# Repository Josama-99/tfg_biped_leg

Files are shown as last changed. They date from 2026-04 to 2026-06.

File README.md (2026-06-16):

# tfg_biped_leg

Bipedal robot leg control using ODrive motor controllers.

## Overview

This package provides control for a 3-DOF bipedal robot leg using:
- **Raspberry Pi** as main controller
- **ODrive v3.6** for motor control
- **TCA9548A** I2C multiplexer
- **AS5600** magnetic encoders for joint position sensing

**Current Status**: Official ODrive working ✅, TCA9548A + AS5600 encoder reading ✅ (with software filter), Makerbase BRICKED ⚠️

# CAD Models

The complete CAD models are available publicly on Onshape:

- Full robot assembly:
https://cad.onshape.com/documents/045d4f9be7d4b5f849aa776b/w/4ef7c623f6d94cfc82375378/e/659acbeabc324ef1581e169c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

- URDF model:
https://cad.onshape.com/documents/ea220f3303c98d0806fc4f15/w/99e78a21887813d82aa56a5b/e/c44cd6904376fa166963b570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

## Architecture

```
┌──────────────────────────────────────────────────────────────────────────────┐
│                              Raspberry Pi                                    │
│  ┌──────────────┐   ┌──────────────┐  ┌──────────────┐  ┌──────────────────┐ │
│  │ Official     │   │ Makerbase    │  │ I2C Mux      │  │ Control Logic    │ │
│  │ ODrive v3.6  │   │ M1 M22015    │  │              │  │                  │ │
│  │ (1 motor)    │   │ (2 motors)   │  │ (Encoders)   │  │                  │ │
│  └──────┬───────┘   └──────┬───────┘  └──────┬───────┘  └──────┬───────────┘ │
└─────────┼──────────────────┼─────────────────┼─────────────────┼─────────────┘
          │                  │                 │                 │
          ▼                  ▼                 ▼                 │
     ┌──────────┐      ┌──────────┐      ┌──────────┐            │
     │ Official │      │ Makerbase│      │TCA9548A  │◄───────────┘
     │ ODrive   │      │ ODrive   │      │I2C Mux   │
     └────┬─────┘      └────┬─────┘      └────┬─────┘
          │                 │                 │
          ▼                 ▼                 ▼
       ┌──────────┐     ┌──────────┐      ┌──────────┬──────────┬──────────┐
       │ D5065    │     │ D5065    │      │ AS5600   │ AS5600   │ AS5600   │
       │ (Hip1)   │     │ (Hip2 +  │      │ (Hip1)   │ (Hip2)   │ (Knee)   │
       │          │     │  Knee)   │      │          │          │          │
       └──────────┘     └──────────┘      └──────────┴──────────┴──────────┘
```

## Hardware

### Current Test Setup (Dual ODrive, 3 Motors)
| Component | Model | Value | Status |
|---|---|---|---|
| Official ODrive | ODrive v3.6 | USB connected (/dev/ttyACM0) | ✅ Working |
| Makerbase ODrive | M1 M22015 | USB DFU mode (0483:df11) | ⚠️ Needs firmware |
| Motors | D5065 | 270 KV | 🔌 Connected |

### Motor Distribution
| ODrive | Motors | Joints |
|---|---|---|
| Official ODrive v3.6 | 1 | Hip 1 (Abduction/Adduction, X-axis) |
| Makerbase M1 M22015 | 2 | Hip 2 (Flexion/Extension, Y-axis) + Knee (Flexion/Extension, Y-axis) |

### Joint Configuration (No Ankle, Ball Foot)
Coordinate system (right leg): +X = Front, +Y = Left, +Z = Up. Fully extended leg points in -Z.
| Joint | Rotation Axis | ODrive | ODrive Axis | Z Offset (from Hip Mount) | Range | Gearbox |
|---|---|---|---|---|---|---|
| Hip 1 (Abduction/Adduction) | X-axis | Official ODrive | 0 | 0mm (0m) | ±45° (±0.79 rad) | 16:1 |
| Hip 2 (Flexion/Extension) | Y-axis | Makerbase ODrive | 0 | -40mm (-0.04m) | ±30° (±0.52 rad) | 16:1 |
| Knee (Flexion/Extension) | Y-axis | Makerbase ODrive | 1 | -390mm (-0.39m) | -90° to 0° (-1.57 to 0 rad) | 16:1 |
| Ball Foot | - | - | - | -740mm (-0.74m) | - | - |

Link lengths: L1=0.04m (Hip1→Hip2), L2=0.35m (Hip2→Knee), L3=0.35m (Knee→Foot), Total hip-to-foot: 0.74m.

### Future Requirements (Full Bipedal Robot - 2 Legs)
| Component | Quantity |
|---|---|
| Makerbase ODrive M1 M22015 | 3 |
| D5065 Motor | 6 |
| AS5600 Encoder | 6 |
| TCA9548A I2C Mux | 2 |

## Installation (Pi Setup)

### 1. Clone the repository
```bash
cd ~/tfg
git clone git@github.com:Josama-99/tfg_biped_leg.git
```

### 2. Install ROS2 Jazzy
```bash
sudo add-apt-repository universe
sudo apt update && sudo apt install curl -y
sudo curl -sSL https://raw.githubusercontent.com/ros/rosdistro/master/ros.key -o /usr/share/keyrings/ros-archive-keyring.gpg
echo "deb [arch=$(dpkg --print-architecture) signed-by=/usr/share/keyrings/ros-archive-keyring.gpg] http://packages.ros.org/ros2/ubuntu \$(. /etc/os-release && echo \$UBUNTU_CODENAME) main" | sudo tee /etc/apt/sources.list.d/ros2.list > /dev/null
sudo apt update
sudo apt install ros-jazzy-ros-base
```

### 3. Create virtual environment
```bash
cd ~/tfg/tfg_biped_leg
sudo apt install python3.12-venv
python3 -m venv tfg_venv
source tfg_venv/bin/activate
pip install --editable .
pip install odrive numpy smbus2 pyyaml colorama matplotlib
```

### 4. Set up ODrive USB permissions
```bash
echo 'SUBSYSTEM=="usb", ATTRS{idVendor}=="0483", ATTRS{idProduct}=="5740", MODE="0666"' | sudo tee /etc/udev/rules.d/50-odrive.rules
sudo udevadm control --reload-rules
```

### 5. Enable I2C on Raspberry Pi (for encoders)
```bash
sudo raspi-config
# → Interface Options → I2C → Enable
sudo apt install i2c-tools python3-smbus
```

## Usage

### Interactive ODrive Test
```bash
source /opt/ros/jazzy/setup.bash
source ~/tfg/tfg_biped_leg/tfg_venv/bin/activate
sudo /home/pi/tfg/tfg_biped_leg/tfg_venv/bin/python3 /home/pi/tfg/odrive_test.py
```

Or run without sudo (after udev rule is applied):
```bash
source /opt/ros/jazzy/setup.bash
source ~/tfg/tfg_biped_leg/tfg_venv/bin/activate
python3 /home/pi/tfg/odrive_test.py
```

### Test Single Motor (automated)
```bash
source /opt/ros/jazzy/setup.bash
source ~/tfg/tfg_biped_leg/tfg_venv/bin/activate
python3 scripts/test_single_motor.py
```

### Calibrate Motors
```bash
source /opt/ros/jazzy/setup.bash
source ~/tfg/tfg_biped_leg/tfg_venv/bin/activate
python3 scripts/calibrate_motors.py
```

### Launch ROS2 Controller
```bash
source /opt/ros/jazzy/setup.bash
source ~/tfg/tfg_biped_leg/tfg_venv/bin/activate
ros2 launch tfg_biped_leg bringup.launch.py
```

## Package Structure

```
tfg_biped_leg/
├── config/                     # Motor configurations
│   └── my_config.json          # D5065 motor settings
├── launch/                     # ROS2 launch files
├── msg/                        # ROS2 messages
├── srv/                        # ROS2 services
├── src/                        # Low-level drivers (TODO)
│   ├── as5600_encoder.py       # AS5600 driver
│   └── i2c_mux.py             # TCA9548A driver
├── tfg_biped_leg/             # Main Python package
│   ├── odrive_interface.py     # ODrive motor control
│   ├── odrive_enums.py         # ODrive enums
│   ├── odrive_driver.py        # ROS2 ODrive driver
│   ├── leg_kinematics.py       # FK/IK
│   └── trajectory_generator.py  # Gait patterns
├── scripts/                    # Utility scripts
│   ├── calibrate_encoder.py    # Encoder calibration + motor control
│   ├── calibrate_motors.py     # Motor calibration
│   ├── odrive_test.py          # Interactive test menu
│   ├── test_encoders.py        # AS5600 encoder test suite
│   └── test_single_motor.py    # Single motor test
└── tests/                      # Unit tests
```

## Motor Configuration

Default settings (`config/my_config.json`):

```json
{
    "current_limit": 30,
    "velocity_limit": 5,
    "calibration_current": 10,
    "pole_pairs": 7,
    "motor_torque_constant": 8.27/270,
    "encoder_cpr": 8192,
}
```

## 3-DOF Joint Configuration (No Ankle)

| Joint | Rotation Axis | ODrive Axis | Z Offset | Range | Gearbox |
|---|---|---|---|---|---|
| Hip 1 (Abduction/Adduction) | X-axis | 0 | 0mm | ±45° (±0.79 rad) | 16:1 |
| Hip 2 (Flexion/Extension) | Y-axis | 0 (Makerbase) | -40mm | ±30° (±0.52 rad) | 16:1 |
| Knee (Flexion/Extension) | Y-axis | 1 (Makerbase) | -390mm | -90° to 0° (-1.57 to 0 rad) | 16:1 |
| Ball Foot | - | - | -740mm | - | - |

Link lengths: L1=0.04m, L2=0.35m, L3=0.35m, Total: 0.74m hip-to-foot.

## URDF Model

The robot geometry is exported from Onshape via `onshape-to-robot` and stored in `urdf/`:

```
urdf/
├── robot.urdf       # Full bipedal robot with 6 joints (right + left leg)
├── config.json      # Onshape document URL for regeneration
└── assets/          # STL mesh files for visualization
```

The URDF uses standard ROS coordinates (X=forward, Y=left, Z=up). All joints have `<axis xyz="0 0 1"/>` in their child frame, with the rpy rotation defining the joint axis direction in the parent frame.

## Kinematics

### Coordinate Convention
The physical robot frame is: X = forward, Y = right, Z = down.  
The DH base frame is: Z₀ = forward (hip abduction axis), X₀ = down, Y₀ = right.

### Denavit-Hartenberg Parameters

| i | aᵢ₋₁ (mm) | αᵢ₋₁ | dᵢ (mm) | θᵢ |
|---|---|---|---|---|
| 1 | L₀ = 40  | +90°  | 0 | θ₁ (hip abduction) |
| 2 | L₁ = 350 | 0° | 0 | θ₂ (hip flexion) |
| 3 | L₂ = 350 | −90°  | 0 | θ₃ (knee flexion) |

### Forward Kinematics

```
x_fwd   = L₁·sin(θ₂) + L₂·sin(θ₂+θ₃)
y_right = (L₀ + L₁·cos(θ₂) + L₂·cos(θ₂+θ₃))·sin(θ₁)
z_down  = (L₀ + L₁·cos(θ₂) + L₂·cos(θ₂+θ₃))·cos(θ₁)
```

At home (θ₁=θ₂=θ₃=0): foot is at (0, 0, 740) mm — straight down, fully extended.

## Encoder Information

### AS5600
- **Type**: Magnetic rotary encoder
- **Resolution**: 12-bit (4096 positions/rev)
- **I2C Address**: 0x36 (all units same)
- **Note**: Requires TCA9548A I2C multiplexer for multiple units

### TCA9548A
- **Channels**: 8 independent I2C buses
- **I2C Address**: 0x70 (default)
- **Purpose**: Enable 3 AS5600 encoders on one Pi I2C bus

### Encoder-based Homing (Virtual End Switches)
The AS5600 is an **absolute encoder** (12-bit, 0-4096 per revolution). Since each joint's mechanical range fits within one revolution (due to the 16:1 gearbox), the AS5600 can serve as a virtual end stop — eliminating the need for physical limit switches.

**Note:** The specific AS5600 unit on channel 5 has an internal CORDIC instability that produces ~215° toggles and periodic ~40° drops. The driver compensates with a median-3 read + jump rejection filter (`JUMP_THRESHOLD = 300`). If replacing the encoder, this can be disabled.

**Calibration (`scripts/calibrate_encoder.py`):**
1. **Manual limits** — Move joint by hand, press `1`/`2`/`3` to record AS5600 raw at limit_min, middle, limit_max.
2. **Auto-calibrate (`a`)** — Script probes motor direction, then slowly approaches each AS5600 limit at 0.3 turns/s. Stops when encoder is within `SAFETY_MARGIN` (50 counts) of the limit, or when motor velocity ≈ 0 for 2s (hit hard stop). Records ODrive motor turns at both limits.
3. **Save (`w`)** — Writes `config/encoder_calibration.yaml` with both encoder raw values and ODrive motor positions. Overwrites on each save.
4. **Oscillate (`o`)** — Sweeps motor between the calibrated motor limits at configurable speed and cycle count.

**Modular arithmetic:** Uses `raw_distance()` to find shortest-path on the 0-4095 circle, so limits that cross the 0/4095 boundary work correctly.

**Homing (every startup):**
1. Read AS5600 raw value for each joint
2. Map to joint angle via stored limits
3. Set ODrive position setpoint — the robot knows its pose without moving

**Virtual end stops:**
- Motor position targets are bounded by `motor_pos_min` / `motor_pos_max`
- No physical limit switches needed

## Testing the ODrive

### Interactive Test Menu

Run the test script:
```bash
sudo /home/pi/tfg/tfg_biped_leg/tfg_venv/bin/python3 /home/pi/tfg/odrive_test.py
```

Menu options:
| Option | Description |
|---|---|
| 1 | Print errors |
| 2 | Print current config |
| 3 | Set default config |
| 4 | Set custom config |
| 5 | Save config |
| 6 | Enable closed loop ✅ |
| 7 | Set torque control |
| 8 | Set position control |
| 9 | Set reference (torque/position) |
| 10 | Live position plot |
| 0 | Exit |

### Calibration Script Menu (calibrate_encoder.py)

| Option | Description |
|---|---|
| 1/2/3 | Record encoder raw at limit_min / middle / limit_max |
| m | Connect ODrive |
| d | Disconnect ODrive |
| a | Auto-calibrate: discover ODrive motor positions at encoder limits |
| o | Oscillate motor between calibrated limits |
| p | Move motor to position (turns) |
| +/- | Step ±0.1 turns |
| w | Save to YAML (overwrites) |
| s/c/q | Show / Clear / Quit |

### How to Make Motor Turn

1. **Select option 6** → Enable closed loop control
2. **Select option 8** → Set position control
3. **Select option 9** → Enter value (e.g., 0.5 for half turn)

---

### Calibration Tool (`scripts/calibrate_encoder.py`)

Combined encoder calibration + motor control script.

```
Usage:
    sudo /home/pi/tfg/tfg_biped_leg/tfg_venv/bin/python3 scripts/calibrate_encoder.py

Menu:
  1/2/3  — Record encoder raw at limit_min / middle / limit_max (move by hand)
  m      — Connect ODrive (uses odrive.find_any(), no re-calibration)
  a      — Auto-calibrate: motor slowly approaches each AS5600 limit, records ODrive turns
  o      — Oscillate motor between calibrated limits
  p      — Move motor to position (turns)
  +/-    — Step ±0.1 turns
  w      — Save calibration to config/encoder_calibration.yaml
  s/c/q  — Show / Clear / Quit

Auto-calibrate safety:
  - Uses position control only (no velocity mode switching)
  - Direction probe: commands +0.5 turns, checks encoder direction
  - Approach: ramps position in 0.03-turn steps every 200ms (~0.15 turns/s)
  - Checks distance to BOTH limits on each step — stops at whichever is within margin
  - First 5 steps skip limit-checking to prevent false re-trigger on the same limit
  - Oscillation waits for motor to actually reach each target (0.05-turn tolerance) before reversing
  - Modular arithmetic handles AS5600 0/4095 wrap
  - SAFETY_MARGIN=100 counts (~8.8°) stops motor before reaching hard stop
  - Ctrl+C aborts at any time
  - Press `e` to print ODrive error codes
```

## Chinese ODrive (Makerbase M1 M22015) - Firmware Issue

The Makerbase ODrive clone controls 2 motors but is currently stuck in DFU mode.

| Parameter | Value |
|---|---|
| Model | M1 M22015 |
| Motors Controlled | 2 (Axis 0 and Axis 1) |
| USB Device | None (stuck in DFU mode) |
| Firmware Status | ⚠️ Flash attempted - stuck in DFU mode |

### Issue Description

The board shows as `0483:df11` (STM32 BOOTLOADER) instead of `0483:5740` (ODrive normal mode).
Firmware flashes complete successfully but the board won't boot into normal mode.

### Firmware Attempted

1. **ODriveFirmware_v3.6-56V.hex** (Makerbase) - Flash succeeded, stuck in DFU
2. **ODriveFirmware_v3.6-56V.elf** (Official v0.5.6) - Flash failed (file too large)
3. **ODriveFirmware_v3.6-24V.hex** (Makerbase) - Flash succeeded, stuck in DFU

### Board Status (2026-04-27)

| Mode | lsusb Result | Status |
|---|---|---|
| DFU | `0483:df11` | ✅ Detected |
| RUN | No device | ❌ Not detected |

**Board is bricked** - needs ST-Link programmer to recover or original Makerbase firmware.

### Firmware Files (2026-04-27)

Downloaded to `/home/pi/tfg/`:
- `ODriveFirmware_v3.6-56V.hex` - Makerbase firmware (649KB)
- `ODriveFirmware_v3.6-56V.elf` - Official ODrive v0.5.6 (6.4MB)

Board detected as **v3.4 or earlier** by odrivetool 0.5.4. Serial: `345331733432`

### Current Status

The Makerbase M1 M22015 board is **bricked**:
- Detected in DFU mode (`0483:df11`) ✅
- NOT detected in RUN mode ❌
- Board serial: `345331733432`
- Board detected as v3.4 hardware

### Recovery Options

1. **ST-Link Programmer** (required for recovery)
2. **Contact Makerbase Support** with serial number
3. **Source original firmware** from teacher
4. **Replace board** with new Makerbase or official ODrive

### Flashing Commands (Legacy - Board Bricked)

These commands are for reference only - the board is currently bricked and cannot be recovered without ST-Link.

```bash
# Install dfu-util
sudo apt-get install dfu-util

# Download firmware (if not already downloaded)
wget https://github.com/makerbase-mks/ODrive-MKS/raw/main/02_Makerbase%20ODrive%20related%20documents/ODriveFirmware_v3.6-56V.hex

# Flash Makerbase firmware (in DFU mode)
sudo dfu-util -a 0 -s 0x08000000:leave -D ODriveFirmware_v3.6-56V.hex

# Download official ODrive firmware
wget https://github.com/odriverobotics/ODrive/releases/download/fw-v0.5.6/ODriveFirmware_v3.6-56V.elf

# Flash official firmware
sudo dfu-util -a 0 -s 0x08000000:leave -D ODriveFirmware_v3.6-56V.elf

# After flash, toggle to RUN mode and check:
lsusb | grep 0483
# Should show 0483:5740 for normal ODrive mode
```

### Reference
- Makerbase GitHub: https://github.com/makerbase-mks/ODrive-MKS
- ODrive Official: https://github.com/odriverobotics/ODrive

## License

MIT License

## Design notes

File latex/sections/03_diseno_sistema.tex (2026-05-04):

\chapter{Diseño del Sistema}

\section{Selección de Componentes}

El sistema se compone de los siguientes elementos principales:

\begin{table}[h]
\centering
\caption{Componentes del Sistema}
\label{tab:componentes}
\begin{tabular}{llll}
\toprule
\textbf{Componente} & \textbf{Modelo} & \textbf{Cantidad} & \textbf{Propósito} \\
\midrule
ODrive v3.6 Oficial & v3.6 & 1 & Control 1 motor (Hip 1) \\
Makerbase ODrive & M1 M22015 & 1 & Control 2 motores (Hip 2 + Knee) \\
Motor BLDC & D5065 270KV & 3 & Actuación (por pierna) \\
Encoder & AS5600 & 3 & Posición articular (por pierna) \\
Multiplexor I2C & TCA9548A & 1 & Lectura de encoders \\
Controlador Principal & Raspberry Pi & 1 & Control de alto nivel \\
\bottomrule
\end{tabular}
\end{table}

\section{Configuración de la Pierna (3-DOF, Sin Tobillo)}

La pierna robótica utiliza un pie de tipo bola (ball foot) y no tiene articulación de tobillo. La configuración de las articulaciones es:

\begin{table}[h]
\centering
\caption{Configuración de Articulaciones}
\label{tab:articulaciones}
\begin{tabular}{lllllll}
\toprule
\textbf{Articulación} & \textbf{Eje Rotación} & \textbf{ODrive} & \textbf{Eje ODrive} & \textbf{Offset Z (m)} & \textbf{Rango (rad)} & \textbf{Reducción} \\
\midrule
Hip 1 (Abd/Add) & X & Oficial & 0 & 0 & $\pm$0.79 & 16:1 \\
Hip 2 (Flex/Ext) & Y & Makerbase & 0 & -0.04 & $\pm$0.52 & 16:1 \\
Knee (Flex/Ext) & Y & Makerbase & 1 & -0.39 & -1.57 a 0 & 16:1 \\
Pie de Bola & - & - & - & -0.74 & - & - \\
\bottomrule
\end{tabular}
\end{table}

Sistema de coordenadas (pierna derecha): +X = Frente, +Y = Izquierda, +Z = Arriba. Pierna extendida apunta en -Z.

Longitudes de eslabones: $L_1 = 0.04$m (Hip1→Hip2), $L_2 = 0.35$m (Hip2→Knee), $L_3 = 0.35$m (Knee→Foot). Total cadera-pie: 0.74m.

\section{Arquitectura del Sistema}

\begin{figure}[h]
\centering
\begin{tikzpicture}[scale=0.8, every node/.style={transform shape}]
% Raspberry Pi
\node[draw, rectangle, minimum width=3cm, minimum height=1cm] (pi) at (0,0) {Raspberry Pi};
% ODrives
\node[draw, rectangle, minimum width=2.5cm, minimum height=0.8cm] (off) at (-2,-2) {ODrive Oficial};
\node[draw, rectangle, minimum width=2.5cm, minimum height=0.8cm] (mk) at (2,-2) {Makerbase ODrive};
% I2C Mux
\node[draw, rectangle, minimum width=2.5cm, minimum height=0.8cm] (mux) at (0,-2) {TCA9548A};
% Control Logic
\node[draw, rectangle, minimum width=3cm, minimum height=0.8cm] (ctrl) at (0,-4) {Control Logic};

% Connections
\draw[->] (pi) -- (off);
\draw[->] (pi) -- (mk);
\draw[->] (pi) -- (mux);
\draw[->] (pi) -- (ctrl);

% Motors
\node[draw, circle, minimum size=1cm] (m1) at (-2,-4) {M1};
\node[draw, circle, minimum size=1cm] (m2) at (2,-4) {M2};
\node[draw, circle, minimum size=1cm] (m3) at (4,-4) {M3};

\draw[->] (off) -- (m1);
\draw[->] (mk) -- (m2);
\draw[->] (mk) -- (m3);

% Encoders
\node[draw, rectangle, minimum width=1.5cm, minimum height=0.6cm] (e1) at (-1,-5.5) {AS5600 \#1};
\node[draw, rectangle, minimum width=1.5cm, minimum height=0.6cm] (e2) at (1,-5.5) {AS5600 \#2};
\node[draw, rectangle, minimum width=1.5cm, minimum height=0.6cm] (e3) at (3,-5.5) {AS5600 \#3};

\draw[->] (mux) -- (e1);
\draw[->] (mux) -- (e2);
\draw[->] (mux) -- (e3);

\end{tikzpicture}
\caption{Arquitectura del Sistema}
\label{fig:arquitectura}
\end{figure}

\section{Especificaciones de los Motores D5065 270KV}

\begin{table}[h]
\centering
\caption{Especificaciones del Motor D5065}
\label{tab:motor_specs}
\begin{tabular}{ll}
\toprule
\textbf{Parámetro} & \textbf{Valor} \\
\midrule
KV Rating & 270 RPM/V \\
Pole Pairs & 7 \\
Torque Constant & 0.0306 Nm/A \\
Encoder CPR & 8192 \\
Current Limit & 30 A \\
Velocity Limit & 5 turn/s \\
\bottomrule
\end{tabular}
\end{table}

Con reductora de 16:1, el par máximo por articulación es: $\tau_{\text{joint}} = 0.0306 \times 30 \times 16 = \SI{14.7}{\newton\meter}$.

\section{Distribución de Masas (Por Pierna)}

\begin{table}[h]
\centering
\caption{Masas de los Componentes (Por Pierna)}
\label{tab:masas}
\begin{tabular}{llll}
\toprule
\textbf{Componente} & \textbf{Cantidad} & \textbf{Masa (g)} & \textbf{Modelo} \\
\midrule
Motor BLDC D5065 & 3 & 1260 & 420g c/u \\
Rodamiento (680) & 15 & 150 & 10g c/u \\
Correa 2GT & 6 & 48 & 8g c/u \\
Encoder AS5600 & 3 & 6 & 2g c/u \\
ODrive v3.6 & 2 & 100 & 50g c/u \\
Raspberry Pi CM4 (parcial) & 0.5 & 60 & 120g total \\
Batería LiPo 6S (parcial) & 0.5 & 310 & 620g total \\
Estructura PETG & 1 & 900 & Impreso 3D \\
Tornillería M3/M4 & 25 & 25 & 1g c/u \\
Cableado & 1 & 50 & Varios \\
\textbf{Total por Pierna} & - & \textbf{2909} & \textbf{~2.9kg} \\
Payload (Torso/Electrónica) & - & 1100 & - \\
\textbf{Total con Payload} & - & \textbf{4000} & \textbf{4kg/pierna} \\
\bottomrule
\end{tabular}
\end{table}

Para un robot de 8kg total, cada pierna soporta 4kg en configuración bilateral (sentadilla con dos pies en el suelo).

\section{Cálculo de Par en Articulaciones (Sentadilla)}

Para calcular el par requerido en cada articulación, se considera un escenario de peor caso donde el robot realiza una sentadilla bilateral (ambos pies en el suelo) con una masa total de \SI{8}{kg}, resultando en \SI{4}{kg} (\SI{39.24}{N}) por pierna. El robot cuenta con una pierna de 3-DOF sin articulación de tobillo, usando un pie de tipo bola para contacto con el suelo.

\subsection{Configuración de la Sentadilla}

Se asume la siguiente pose para la sentadilla (sentadilla bilateral, distribución de carga igualitaria):

\begin{itemize}
    \item Abducción de Hip 1 (eje X): 0° = 0 rad (simétrica, sin carga lateral)
    \item Flexión de Hip 2 (eje Y): 60° = 1.047 rad
    \item Flexión de Knee (eje Y): 90° = 1.571 rad
    \item Centros de masa de los eslabones: En el punto medio de cada eslabón (0.02m, 0.175m, 0.175m desde la articulación proximal)
    \item Contacto con el suelo: Pie de bola a 0.74m por debajo del punto de montaje de la cadera
\end{itemize}

\subsection{Cálculo de Par}

El par en cada articulación se calcula usando equilibrio estático: $\tau = \sum m_i \cdot g \cdot d_{i,\perp}$, donde $d_{i,\perp}$ es la distancia horizontal desde la articulación hasta el centro de masa de cada carga (perpendicular a la gravedad).

\textbf{Articulación Knee (eje Y, Flexión/Extensión):}
\begin{align*}
d_{\text{suelo}} &= 0.175\,\text{m} \quad \text{(CoM en punto medio del eslabón)} \\
\tau_{\text{suelo}} &= 39.24\,\text{N} \times 0.175\,\text{m} = 6.87\,\text{Nm} \\
\tau_{\text{pantorrilla}} &= 0.99\,\text{kg} \times 9.81\,\text{m/s}^2 \times 0.0875\,\text{m} = 0.85\,\text{Nm} \\
\tau_{\text{Knee}} &= 6.87 + 0.85 = \mathbf{7.72\,\text{Nm}}
\end{align*}

\textbf{Articulación Hip 1 (eje X, Abducción/Adducción):}
\begin{align*}
\tau_{\text{Hip 1}} &= 0\,\text{Nm} \quad \text{(sentadilla simétrica, sin carga en plano frontal)}
\end{align*}

\textbf{Articulación Hip 2 (eje Y, Flexión/Extensión):}
\begin{align*}
d_{\text{suelo}} &= 0.04 + 0.35 \times \sin(90^\circ) + 0.175 = 0.565\,\text{m} \\
\tau_{\text{distal}} &= 39.24\,\text{N} \times 0.565\,\text{m} = 22.17\,\text{Nm} \\
\tau_{\text{muslo}} &= 1.49\,\text{kg} \times 9.81\,\text{m/s}^2 \times 0.02\,\text{m} = 0.29\,\text{Nm} \\
\tau_{\text{Hip 2}} &= 22.17 + 0.29 = \mathbf{22.46\,\text{Nm}}
\end{align*}

\textbf{Articulación Hip 2 (eje Y, Abducción/Adducción):}
\begin{align*}
\tau_{\text{Hip 2}} &= 0\,\text{Nm} \quad \text{(sentadilla simétrica, sin carga en plano frontal)}
\end{align*}

\textbf{Articulación Hip 1 (eje X, Flexión/Extensión):}
\begin{align*}
d_{\text{suelo}} &= 0.04 + 0.35 \times \sin(90^\circ) + 0.175 = 0.565\,\text{m} \\
\tau_{\text{distal}} &= 39.24\,\text{N} \times 0.565\,\text{m} = 22.17\,\text{Nm} \\
\tau_{\text{muslo}} &= 1.49\,\text{kg} \times 9.81\,\text{m/s}^2 \times 0.02\,\text{m} = 0.29\,\text{Nm} \\
\tau_{\text{Hip 1}} &= 22.17 + 0.29 = \mathbf{22.46\,\text{Nm}}
\end{align*}

\subsection{Resultados y Capacidad del ODrive}

\begin{table}[h]
\centering
\caption{Resultados de Par por Articulación vs Capacidad ODrive}
\label{tab:torque_results}
\begin{tabular}{lccc}
\toprule
\textbf{Articulación} & \textbf{Par Requerido} & \textbf{Capacidad ODrive (16:1)} & \textbf{Estado} \\
\midrule
Hip 1 (eje X, Abd/Add) & 0 Nm & 14.7 Nm & \textcolor{green}{Suficiente} \\
Hip 2 (eje Y, Flex/Ext) & 22.46 Nm & 14.7 Nm & \textcolor{red}{Insuficiente} \\
Knee (eje Y, Flex/Ext) & 7.72 Nm & 14.7 Nm & \textcolor{green}{Suficiente} \\
\bottomrule
\end{tabular}
\end{table}

\textbf{Nota:} La articulación Hip 2 (eje Y, flexión/extensión) excede la capacidad del ODrive (22.46 Nm requeridos vs 14.7 Nm disponibles). La articulación Hip 1 (eje X, abducción/aducción) es suficiente con 0 Nm en sentadilla simétrica. Para una sentadilla unipodal (8kg en una pierna), los pares se duplicarían, haciendo que Hip 2 y potencialmente Knee sean insuficientes. Las soluciones incluyen aumentar la relación de reducción de Hip 2 a 25:1 o reducir la carga útil/profundidad de la sentadilla.

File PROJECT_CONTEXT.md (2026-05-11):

# Project Context - tfg_biped_leg

**Last Updated**: 2026-04-27 (Created TFG_PROMPT.md for LaTeX document generation)

## Project Overview

- **Project Name**: tfg_biped_leg
- **Purpose**: Control a bipedal robot leg using ODrive motor controllers
- **Type**: Single leg prototype (3-DOF, expandable to full bipedal robot)
- **Hardware**: Raspberry Pi + ODrive v3.6 + AS5600 Encoders + TCA9548A Mux
- **Status**: ODrive connected ✅, Motor testing in progress ✅

---

## GitHub Repository

| Field | Value |
|---|---|
| **Username** | Josama-99 |
| **Repo URL** | https://github.com/Josama-99/tfg_biped_leg |
| **Status** | ✅ Synced with local |

---

## Architecture

### Current Setup: Pi + Dual ODrive (USB)

```
┌──────────────────────────────────────────────────────────────────────────────┐
│                              Raspberry Pi                                    │
│  ┌──────────────┐  ┌──────────────┐  ┌──────────────┐  ┌──────────────────┐ │
│  │ Official     │  │ Makerbase    │  │ I2C Mux      │  │ Control Logic    │ │
│  │ ODrive v3.6  │  │ M1 M22015    │  │              │  │                  │ │
│  │ (1 motor)    │  │ (2 motors)   │  │ (Encoders)   │  │                  │ │
│  └──────┬───────┘  └──────┬───────┘  └──────┬───────┘  └────────┬─────────┘ │
└─────────┼──────────────────┼──────────────────┼─────────────────┼──────────┘
           │                  │                  │                  │
           ▼                  ▼                  ▼                  │
      ┌──────────┐      ┌──────────┐      ┌──────────┐            │
      │ Official │      │ Makerbase│      │TCA9548A  │◄───────────┘
      │ ODrive   │      │ ODrive   │      │I2C Mux   │
      └────┬─────┘      └────┬─────┘      └────┬─────┘
           │                 │                 │
           ▼                 ▼                 ▼
       ┌──────────┐     ┌──────────┐      ┌──────────┬──────────┬──────────┐
       │ D5065    │     │ D5065    │      │ AS5600   │ AS5600   │ AS5600   │
       │ Motor    │     │ Motors   │      │ (Hip1)   │ (Hip2)   │ (Knee)   │
       └──────────┘     └──────────┘      └──────────┴──────────┴──────────┘
```

### Control Stack

| Level | Component | Purpose |
|---|---|---|
| 1 | Official ODrive v3.6 | 1 motor closed-loop control |
| 1 | Makerbase M1 M22015 | 2 motors closed-loop control |
| 2 | USB | Communication Pi → ODrives |
| 3 | Raspberry Pi | High-level control, kinematics, trajectories |
| 4 | TCA9548A | I2C multiplexer for 3 encoders |
| 5 | AS5600 ×3 | Joint position sensing (after gearbox) |

---

## Key Decisions

| Decision | Value | Date | Notes |
|---|---|---|---|
| Project Name | tfg_biped_leg | 2026-04-12 | |
| Robot Type | Single leg prototype | 2026-04-12 | Expandable to bipedal |
| Motors per Leg | 3-DOF | 2026-04-12 | Hip 1, Hip 2, Knee (no ankle) |
| ODrive Model | Official v3.6 + Makerbase M1 M22015 | 2026-04-24 | Official: 1 motor, Makerbase: 2 motors |
| Encoder Type | AS5600 | 2026-04-12 | Magnetic, 12-bit |
| I2C Mux | TCA9548A | 2026-04-12 | Needed for 3 encoders |
| Control Method | Pi direct | 2026-04-12 | No Teensy |
| Communication | USB (ODrive) + I2C (Encoders) | 2026-04-12 | |
| Programming | Python | 2026-04-12 | + ROS2 structure |
| SSH Access | ed25519 | 2026-04-13 | jordisanchezmartori@gmail.com |
| Virtual Env | tfg_venv | 2026-04-13 | Python 3.12 |
| ROS2 Distro | Jazzy | 2026-04-13 | Ubuntu 24.04 |

---

## Hardware Configuration

### Current Test Setup (Dual ODrive, 3 Motors)

| Component | Model | Value | Status |
|---|---|---|---|
| Official ODrive | ODrive v3.6 | USB connected (/dev/ttyACM0) | ✅ Ready |
| Makerbase ODrive | M1 M22015 | USB DFU mode (0483:df11) | ⚠️ Needs firmware fix |
| Motors | D5065 | 270 KV | 🔌 Connected |
| Power | 12V | DC supply | ⚡ Powered |
| Serial (Official) | 35790927514957 | ODrive S/N | ✅ Connected |

### Current Hardware (3-DOF Leg - 3 Motors)

| Component | Quantity | Model | Purpose |
|---|---|---|---|
| Official ODrive v3.6 | 1 | Official v3.6 | 1 motor control |
| Makerbase ODrive M1 M22015 | 1 | Chinese clone | 2 motors control |
| Motor | 3 | D5065 270KV | Actuation |
| AS5600 | 3 | Magnetic encoder | Joint position |
| TCA9548A | 1 | I2C Mux | Encoder multiplexing |
| Raspberry Pi | 1 | Any | Main controller |

### Motor Specifications (D5065 270KV)

| Parameter | Value |
|---|---|
| KV Rating | 270 RPM/V |
| Pole Pairs | 7 |
| Torque Constant | 8.27/270 Nm/A (≈0.0306 Nm/A) |
| Encoder CPR | 8192 (built-in) |
| Current Limit | 30A |
| Velocity Limit | 5 turn/s |

### AS5600 Encoder Specifications

| Parameter | Value |
|---|---|
| Type | Magnetic rotary encoder |
| Resolution | 12-bit (4096 positions/rev) |
| I2C Address | 0x36 (all units same) |
| Communication | I2C (requires mux for multiple) |

### TCA9548A I2C Multiplexer

| Parameter | Value |
|---|---|
| Channels | 8 independent I2C buses |
| I2C Address | 0x70 (default) |
| Purpose | Enable multiple AS5600 on one bus |

### Encoder-based Homing (Virtual End Switches)

The AS5600 absolute encoder replaces physical limit switches:

**Why it works:**
- AS5600 is absolute (remembers position after power cycle)
- 12-bit resolution = 4096 positions per revolution
- Each joint's mechanical range fits within one revolution (16:1 gearbox means 1 joint rev = 16 motor revs)
- So each AS5600 value maps uniquely to a joint angle with no ambiguity

**Procedure:**
1. **Manual calibration** (one-time): Move joint by hand to limit 1, middle, limit 2. Record AS5600 raw values.
2. **Auto-calibrate** (one-time, `a` key in `calibrate_encoder.py`): Script probes motor direction, then slowly moves the motor toward each AS5600 limit until either (a) the encoder reads within `SAFETY_MARGIN` of the limit, or (b) the motor stalls (velocity ≈0 for 2s = hit hard stop). ODrive motor turns are recorded for both limits.
3. **Homing** (every startup): Read AS5600 → map to joint angle via stored limits → set ODrive position setpoint.
4. **Virtual end stops** (runtime): Clamp all position targets within the recorded motor limits.
5. **Oscillation** (`o` key in `calibrate_encoder.py`): Sweep motor between `motor_pos_min` and `motor_pos_max` at configurable speed/cycles for testing.

**Key details:**
- **Modular arithmetic** (`raw_distance()`): Handles AS5600 0/4095 wrap if the mechanical range crosses the boundary. All distance calculations use shortest-path on the circle.
- **Safety margin** (50 counts, ~4.4°): The motor stops approaching when encoder is within this margin of the recorded limit, preventing wear against hard stops.
- **Stall detection**: If motor velocity is below `STALL_VEL_THRESHOLD` (0.01 turns/s) for `STALL_TIMEOUT` (2s), the motor has hit the physical limit. The current motor position is recorded as the limit value.

---

## Joint Definitions

### 3-DOF Leg Configuration (No Ankle, Ball Foot)

The physical robot frame uses: X = forward, Y = right, Z = down.  
The DH base frame is: Z₀ = forward (hip abduction axis), X₀ = down, Y₀ = right.

| Joint | Rotation Axis | ODrive | Motor Axis | Z Offset (from Hip Mount) | Encoder | Typical Range | Gearbox |
|---|---|---|---|---|---|---|---|
| Hip 1 (Abduction/Adduction) | X-axis | Official ODrive | 0 | 0mm (0m) | AS5600 #1 | ±45° (±0.79 rad) | 16:1 |
| Hip 2 (Flexion/Extension) | Y-axis | Makerbase ODrive | 0 | -40mm (-0.04m) | AS5600 #2 | ±30° (±0.52 rad) | 16:1 |
| Knee (Flexion/Extension) | Y-axis | Makerbase ODrive | 1 | -390mm (-0.39m) | AS5600 #3 | -90° to 0° (-1.57 to 0 rad) | 16:1 |
| Ball Foot | - | - | - | -740mm (-0.74m) | - | - | - |

Link lengths: L₀=0.04m (Hip1→Hip2), L₁=0.35m (Hip2→Knee), L₂=0.35m (Knee→Foot), Total hip-to-foot: 0.74m.

> **Note**: Joint assignments verified. Official ODrive controls 1 motor (Hip1), Makerbase controls 2 motors (Hip2 + Knee).

### Denavit-Hartenberg Parameters

Z₀ is chosen as forward (aligned with hip abduction axis) rather than vertical, because standard DH requires Zᵢ as the joint axis. Hip abduction rotates about the forward direction, so Z₀ = forward. At home the leg hangs straight down, so X₀ = down. α₀ = +90° rotates Z₀ → Z₁ (lateral, hip flexion axis). α₂ = −90° rotates Z₂ (lateral) back to Z₃ ≈ forward, matching the base frame orientation.

| i | aᵢ₋₁ (mm) | αᵢ₋₁ | dᵢ (mm) | θᵢ |
|---|---|---|---|---|
| 1 | L₀ = 40  | +90°  | 0 | θ₁ (hip abduction) |
| 2 | L₁ = 350 | 0° | 0 | θ₂ (hip flexion) |
| 3 | L₂ = 350 | −90°  | 0 | θ₃ (knee flexion) |

### Forward Kinematics

In the physical robot frame (X=forward, Y=right, Z=down):

```
x_fwd   = L₁·sin(θ₂) + L₂·sin(θ₂+θ₃)
y_right = (L₀ + L₁·cos(θ₂) + L₂·cos(θ₂+θ₃))·sin(θ₁)
z_down  = (L₀ + L₁·cos(θ₂) + L₂·cos(θ₂+θ₃))·cos(θ₁)
```

At home (θ₁=θ₂=θ₃=0): (x, y, z) = (0, 0, L₀+L₁+L₂) = (0, 0, 740) mm.

### URDF Model

The Onshape assembly is exported to `urdf/robot.urdf` (ROS coordinates: X=forward, Y=left, Z=up). All joints use `<axis xyz="0 0 1"/>` in the child frame; the rpy of each joint origin defines the axis direction in the parent frame. See `scripts/dh_kinematics.py` for the numeric comparison between URDF-based FK and the simplified DH model.

### Gearbox Conversion

```
joint_turns = motor_turns / 16  (16:1 reduction)
motor_turns = joint_turns × 16
```

---

## Project Status

### Current Status: 🚧 Makerbase Bricked - Continue with Official ODrive

- [x] Project structure created ✅
- [x] All Python modules implemented ✅
- [x] ROS2 integration complete ✅
- [x] Initial commit created ✅
- [x] Git repository initialized ✅
- [x] SSH key setup ✅
- [x] Push to GitHub ✅
- [x] Code copied from USB (odrive_smapy) ✅
- [x] Test script created ✅
- [x] Official ODrive connected via USB ✅
- [x] Virtual environment set up ✅
- [x] ROS2 Jazzy installed ✅
- [x] Python dependencies installed ✅
- [x] Official ODrive calibration complete ✅
- [x] Makerbase ODrive acquired ✅
- [x] Makerbase connected via USB (DFU mode) ✅
- [x] dfu-util installed ✅
- [x] Firmware downloaded ✅
- [x] Multiple firmware flash attempts - board bricked ⚠️
- [ ] Recover Makerbase ODrive (needs ST-Link)
- [x] Test encoder reading ✅ (2026-05-08)
- [ ] Integrate encoder with motor control (future)
- [ ] Add more motors (expand to 3-DOF)

### Components Status

| Component | Status | Notes |
|---|---|---|
| ODrive ODrive Class | ✅ | USB motor control (Official) |
| ODrive Enums | ✅ | State/error definitions |
| ODrive Driver (ROS2) | ✅ | ROS2 wrapper |
| Forward Kinematics | ✅ | Position from angles |
| Inverse Kinematics | ✅ | Angles from position |
| Trajectory Generator | ✅ | Walking gait patterns |
| ROS2 Integration | ✅ | Topics, services, launch |
| Motor Calibration | ✅ | Script ready |
| Single Motor Test | ✅ | Script ready, Official ODrive connected |
| Interactive Test | ✅ | odrive_test.py |
| Unit Tests | ✅ | Kinematics tests |
| EncoderInterface (Base) | ✅ | Abstract base class |
| TCA9548A Driver | ✅ | I2C mux helper |
| PiAS5600Encoder | ✅ | Pi I2C implementation (working on ch5) |
| SerialEncoder | ✅ | Placeholder for future |
| EncoderManager | ✅ | Factory for multiple encoders |
| Makerbase ODrive Support | 🔧 In Progress | Needs testing |

---

## Pi Setup Completed

### Virtual Environment
```bash
cd ~/tfg/tfg_biped_leg
python3 -m venv tfg_venv
source tfg_venv/bin/activate
pip install -e .
pip install odrive numpy smbus2 pyyaml colorama matplotlib
```

### ODrive USB Permissions
```bash
echo 'SUBSYSTEM=="usb", ATTRS{idVendor}=="0483", ATTRS{idProduct}=="5740", MODE="0666"' | sudo tee /etc/udev/rules.d/50-odrive.rules
sudo udevadm control --reload-rules
```

### Running Tests
```bash
# Interactive test
sudo /home/pi/tfg/tfg_biped_leg/tfg_venv/bin/python3 /home/pi/tfg/odrive_test.py
```

---

## TODO

### High Priority
- [x] Test single motor with official ODrive v3.6 ✅
- [x] Official ODrive USB connected ✅
- [x] Calibration complete (Official ODrive) ✅
- [ ] Connect Makerbase ODrive via USB
- [ ] Test Makerbase connection and verify device path
- [ ] Check Makerbase firmware version
- [x] Test encoder reading ✅
- [x] Encoder + motor integration (calibrate_encoder.py) ✅

### Medium Priority
- [ ] Verify kinematics with physical leg
- [ ] Add motors and expand to 3-DOF
- [ ] Implement closed-loop position control with encoder feedback
- [ ] Handle AS5600 wrap-around with modular arithmetic (implemented in calibrate_encoder.py)
- [ ] Add stall detection as safety backstop in auto-calibrate (implemented in calibrate_encoder.py)

### Low Priority
- [ ] Create walking gait trajectories
- [ ] Test leg movement
- [ ] Expand to 2-leg (bipedal) configuration

---

## First Use Checklist

1. [x] Project setup (code downloaded)
2. [x] Set ODrive USB permissions
 3. [x] Enable I2C on Pi (`sudo raspi-config` → Interface → I2C) ✅
4. [x] Install dependencies (pip install odrive numpy smbus2 pyyaml)
5. [x] Connect Official ODrive via USB
6. [x] Run motor calibration
7. [x] Test single motor
8. [ ] Connect Makerbase ODrive via USB
9. [ ] Verify Makerbase device path (dmesg | grep tty)
10. [ ] Test Makerbase connection
11. [x] Connect TCA9548A and verify with `sudo i2cdetect -y 1` ✅
12. [x] Connect AS5600 encoder to mux channel 5 ✅
13. [x] Test encoder reading (`python3 scripts/test_encoders.py --channels 5`) ✅
14. [x] Encoder + motor control (calibrate_encoder.py) ✅
    1. Record 3 manual encoder limits (1/2/3 keys)
    2. Connect ODrive (`m` key)
    3. Auto-calibrate motor positions (`a` key)
    4. Oscillate safely between limits (`o` key)

---

## Makerbase ODrive M1 M22015 - Status: BRICKED

The Chinese Makerbase ODrive M1 M22015 clone is **bricked** and currently unusable. All firmware flash attempts have failed to bring the board into normal operation mode.

| Parameter | Value |
|---|---|
| Model | M1 M22015 |
| Manufacturer | Makerbase |
| Motors Controlled | 2 (Axis 0 and Axis 1) |
| USB Device (DFU) | `0483:df11` detected ✅ |
| USB Device (RUN) | No device detected ❌ |
| Firmware Status | ⚠️ BRICKED - needs ST-Link recovery |

### USB Detection by Mode

| Switch Mode | lsusb | Status |
|---|---|---|
| DFU | `0483:df11` (STM32 BOOTLOADER) | ✅ Detected |
| RUN | No device | ❌ NOT detected |

### Firmwares Tried

| Firmware | Size | Result |
|---|---|---|
| ODriveFirmware_v3.6-56V.hex (Makerbase) | 649KB | Flash OK, no RUN mode |
| ODriveFirmware_v3.6-56V.elf (Official v0.5.6) | 6.4MB | Flash failed (file too large) |
| ODriveFirmware_v3.6-24V.hex (Makerbase) | 649KB | Flash OK, no RUN mode |

### Root Cause

- Board detected as v3.4 hardware (odrivetool 0.5.4)
- Official .elf firmware too large for board flash memory
- .hex firmware flashes successfully but board won't boot into normal mode
- Bootloader may be corrupted or incompatible with available firmware

### Recovery Options

1. **ST-Link Programmer** - Required to recover (not available)
2. **Contact Makerbase Support** - Provide serial `345331733432`
3. **Source Original Firmware** - Teacher doesn't remember which firmware
4. **Replace Board** - Order new Makerbase M1 M22015 or official ODrive

### Current Workaround

Continue development with official ODrive v3.6 (1 motor).
Makerbase board on hold until recovery solution found.

See also: https://github.com/makerbase-mks/ODrive-MKS

### Resources
- ODrive v0.5.6 `odrivetool` docs (firmware update & troubleshooting): https://docs.odriverobotics.com/v/0.5.6/odrivetool.html#troubleshooting

---

## Reference Repositories

### Private (pending)
- **odrive_smapy** by SergiMuac
  - URL: https://github.com/SergiMuac/odrive_smapy
  - Purpose: Motor control code reference
  - Status: Private, clone as git submodule when accessible

### Public Dependencies
- **ODrive**: https://github.com/odriverobotics/ODrive
  - Firmware v0.5.x compatible
- **ros_odrive**: https://github.com/odriverobotics/ros_odrive
  - ROS2 integration
- **Makerbase ODrive**: https://github.com/makerbase-mks/ODrive-MKS
  - Chinese clone firmware
- **ODrive v0.5.6 Firmware Update Docs**: https://docs.odriverobotics.com/v/0.5.6/odrivetool.html#device-firmware-update
  - Troubleshooting, forcing DFU mode, alternative DFU tools, ST-Link flashing

---

## User Information

- **Platform**: Raspberry Pi (Ubuntu 24.04)
- **Username**: pi
- **Working Directory**: /home/pi/tfg/
- **GitHub**: Josama-99
- **Email**: jordisanchezmartori@gmail.com

---

## Change Log

### 2026-05-10
- `calibrate_encoder.py` — multiple fixes:
  - Auto-calibrate now checks distance to BOTH limits on each step (`approach_any_limit`)
  - Skip first 5 steps of limit-checking to avoid false re-trigger on the same limit when reversing direction
  - Added `print_odrive_errors()` + `e` key and error display in status
  - Removed stall detection (was false-triggering mid-range)
  - Oscillation (`o`) now polls `pos_estimate` with 0.05-turn tolerance instead of fixed timer — motor actually arrives at each limit before reversing
  - Reduced ramp speed to 0.03 turns/step (0.15 turns/s) for precise limit approach
  - `connect_odrive()` now runs full calibration sequence before closed-loop (fixes motor not moving)
  - SAFETY_MARGIN set to 100 counts (~8.8°)
- Oscillation mode (`o`): sweeps motor between calibrated limits at configurable speed/cycles
- Modular arithmetic (`raw_distance()`) handles AS5600 0/4095 wrap for cross-boundary ranges
- Manual position control (`p`), fine stepping (`+`/`-`), safety margin (50 counts)
- ODrive connects directly (`odrive.find_any()`) bypassing IOdrive to avoid re-calibration
- YAML saves both encoder raw values and ODrive motor positions (overwritable)

### 2026-05-08
- Fixed AS5600 CORDIC toggle (215° chip-level jumps) → median-3 + jump threshold filter
- Fixed periodic I2C bursts (~400 count drops every ~15s) → same filter catches both
- Encoder readings now stable and clean
- Recordings saved to recordings/ with timestamped files

### 2026-05-08 (earlier)
- TCA9548A I2C multiplexer verified working
- AS5600 encoder tested on mux channel 5
- Live plotting script created (plot_encoder.py)
- Encoder reads angle + magnet status successfully via smbus2
- Encoder skips detected (likely magnet misalignment - needs investigation)

### 2026-04-27 (continued)
- Board remains bricked: detected in DFU mode but not in RUN mode
- Tried firmware variants: ODriveFirmware_v3.6-56V.hex, ODriveFirmware_v3.6-56V.elf, ODriveFirmware_v3.6-24V.hex
- .elf files too large for board flash memory
- .hex files flash successfully but board won't boot into normal mode
- Board switch toggles between DFU/RUN but RUN mode shows no USB device
- **Board needs ST-Link programmer to recover** or replacement firmware from Makerbase
- Teacher does not have original firmware
- Next step: Contact Makerbase support or order replacement board

### 2026-04-27
- Acquired Makerbase M1 M22015 Chinese ODrive clone
- Updated project to use dual ODrive configuration:
  - Official ODrive v3.6: 1 motor (Hip - TBD)
  - Makerbase ODrive: 2 motors (Hip 2 + Knee - TBD)
- Documentation updated to reflect dual ODrive setup
- Makerbase firmware flashing attempts:
  - Installed dfu-util
  - Downloaded MKS ODrive_S-fw-v0.5.1 firmware
  - Downloaded ODriveFirmware_v3.6-56V firmware
  - Flash of MKS firmware succeeded but board stuck in DFU mode
  - Flash of 56V firmware succeeded but board stuck in DFU mode
- Board persists in DFU mode (0483:df11) instead of normal mode (0483:5740)
- Next step: Get original working firmware from teacher

### 2026-04-13
- ODrive v3.6 connected via USB
- Serial number: 35790927514957
- Virtual environment tfg_venv created
- ROS2 Jazzy installed
- Python dependencies (odrive, numpy, smbus2, pyyaml, colorama, matplotlib) installed
- odrive_test.py interactive script created
- Motor calibration successful (axis1)
- Motor testing in progress

### 2026-04-12
- Project initialized
- All source files created
- Git repository initialized with initial commit
- GitHub repo created (Josama-99/tfg_biped_leg)
- SSH keys generated (ed25519)
- GitHub push complete
- Code copied from USB (odrive_smapy-main)

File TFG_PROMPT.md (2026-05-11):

# Prompt for TFG LaTeX Document Generation

## Context
You are helping a university student (TFG - Trabajo de Fin de Grado / Final Degree Project) create a LaTeX document (memoria) for a bipedal robot leg control project. Below is all the project information.

---

## Project Title (Suggestion)
Control de una pierna robótica bípeda de 3-DOF usando controladores ODrive

(Control of a 3-DOF bipedal robot leg using ODrive motor controllers)

## Student Information
- **GitHub**: https://github.com/Josama-99
- **Email**: jordisanchezmartori@gmail.com
- **Platform**: Raspberry Pi (Ubuntu 24.04)
- **Hostname**: robopi

---

## Project Overview

**Purpose**: Control a bipedal robot leg using ODrive motor controllers  
**Type**: Single leg prototype (3-DOF, expandable to full bipedal robot)  
**Status**: Official ODrive working, Makerbase ODrive needs firmware fix

### Hardware Components

| Component | Model | Quantity | Purpose |
|---|---|---|---|
| Official ODrive | v3.6 | 1 | 1 motor control |
| Makerbase ODrive | M1 M22015 | 1 | 2 motors control (Chinese clone) |
| Motor | D5065 270KV | 3 | Actuation |
| Encoder | AS5600 | 3 | Magnetic joint position sensing |
| I2C Mux | TCA9548A | 1 | Encoder multiplexing |
| Main Controller | Raspberry Pi | 1 | High-level control |

### Component Mass Table (Per Leg, 8kg Total Robot)
| Component | Qty (per leg) | Mass (per unit, g) | Total Mass (per leg, g) | Material/Model |
|---|---|---|---|---|
| Brushless Motor (D5065 270KV) | 3 | 420 | 1260 | D5065 270kv |
| Bearing (680 series) | 15 | 10 | 150 | 10x19x5mm |
| 2GT Belt (10×200mm) | 6 | 8 | 48 | Polyurethane |
| Magnetic Encoder (AS5600) | 3 | 2 | 6 | AS5600 + Magnet |
| ODrive v3.6 Controller | 2 | 50 | 100 | Official/Makerbase |
| Raspberry Pi CM4 | 0.5 | 120 | 60 | Split between legs |
| LiPo 6S Battery | 0.5 | 620 | 310 | Split between legs |
| 3D Printed PETG Structure | 1 | 900 | 900 | PETG Filament |
| M3/M4 Bolts | 25 | 1 | 25 | Stainless Steel |
| Wiring/Connectors | 1 | 50 | 50 | Misc |
| **Total Per Leg** | - | - | **2909g (~2.9kg)** | - |
| **Payload (Torso/Electronics)** | - | 1100g | 1100g | - |
| **Total Per Leg (with Payload)** | - | - | **4kg** | Matches 8kg total |

### Motor Specifications (D5065 270KV)

| Parameter | Value |
|---|---|
| KV Rating | 270 RPM/V |
| Pole Pairs | 7 |
| Torque Constant | 8.27/270 Nm/A (≈0.0306 Nm/A) |
| Encoder CPR | 8192 |
| Current Limit | 30A |
| Velocity Limit | 5 turn/s |

### Encoder Specifications (AS5600)

| Parameter | Value |
|---|---|
| Type | Magnetic rotary encoder |
| Resolution | 12-bit (4096 positions/rev) |
| I2C Address | 0x36 |
| Communication | I2C (requires TCA9548A mux for multiple) |

### I2C Multiplexer (TCA9548A)

| Parameter | Value |
|---|---|
| Channels | 8 independent I2C buses |
| I2C Address | 0x70 |

### Joint Configuration (3-DOF Leg, No Ankle)

**Physical robot frame:** X = forward, Y = right, Z = down.  
**DH base frame:** Z₀ = forward (hip abduction axis), X₀ = down, Y₀ = right.  
(Standard DH with Z₀ vertical cannot represent hip abduction, because α rotation only redirects Z in the Y-Z plane.)

| Joint | Rotation Axis | ODrive | ODrive Axis | Z Offset (from Hip Mount) | Range | Gearbox | Encoder |
|---|---|---|---|---|---|---|---|
| Hip 1 (Abduction/Adduction) | X-axis | Official ODrive | 0 | 0mm (0m) | ±45° (±0.79 rad) | 16:1 | AS5600 #1 |
| Hip 2 (Flexion/Extension) | Y-axis | Makerbase ODrive | 0 | -40mm (-0.04m) | ±30° (±0.52 rad) | 16:1 | AS5600 #2 |
| Knee (Flexion/Extension) | Y-axis | Makerbase ODrive | 1 | -390mm (-0.39m) | -90° to 0° (-1.57 to 0 rad) | 16:1 | AS5600 #3 |
| Ball Foot | - | - | - | -740mm (-0.74m) | - | - | - |

Link lengths: L₀=0.04m (Hip1→Hip2), L₁=0.35m (Hip2→Knee), L₂=0.35m (Knee→Foot), Total hip-to-foot: 0.74m.

### Denavit-Hartenberg Parameters

Z₀ = forward (abduction axis), X₀ = down (gravity direction), Y₀ = right.  
α₀ = +90° rotates Z₀ → Z₁ (lateral, flexion axis). α₂ = −90° rotates Z₂ back to Z₃ ≈ forward.

| i | aᵢ₋₁ (mm) | αᵢ₋₁ | dᵢ (mm) | θᵢ |
|---|---|---|---|---|
| 1 | L₀ = 40  | +90°  | 0 | θ₁ |
| 2 | L₁ = 350 | 0° | 0 | θ₂ |
| 3 | L₂ = 350 | −90°  | 0 | θ₃ |

A₁ = R_z(θ₁)·T_x(L₀)·R_x(+90°),  A₂ = R_z(θ₂)·T_x(L₁),  A₃ = R_z(θ₃)·T_x(L₂)·R_x(−90°)

T = A₁·A₂·A₃ → foot position in DH base:
```
p_DH = [c₁(L₀+L₁c₂+L₂c₂₃),  s₁(L₀+L₁c₂+L₂c₂₃),  L₁s₂+L₂s₂₃]ᵀ
```
Physical frame (X=fwd, Y=right, Z=down):
```
x_fwd   = L₁·s₂ + L₂·s₂₃
y_right = (L₀ + L₁·c₂ + L₂·c₂₃)·s₁
z_down  = (L₀ + L₁·c₂ + L₂·c₂₃)·c₁
```
At home: (0, 0, 740) mm.

---

## Architecture

```
┌──────────────────────────────────────────────────────────────────────────────┐
│                              Raspberry Pi                                    │
│  ┌──────────────┐  ┌──────────────┐  ┌──────────────┐  ┌──────────────────┐ │
│  │ Official     │  │ Makerbase    │  │ I2C Mux      │  │ Control Logic    │ │
│  │ ODrive v3.6  │  │ M1 M22015    │  │              │  │                  │ │
│  │ (1 motor)    │  │ (2 motors)   │  │ (Encoders)   │  │                  │ │
│  └──────┬───────┘  └──────┬───────┘  └──────┬───────┘  └────────┬─────────┘ │
└─────────┼──────────────────┼──────────────────┼─────────────────┼──────────┘
           │                  │                  │                  │
           ▼                  ▼                  ▼                  │
      ┌──────────┐      ┌──────────┐      ┌──────────┐            │
      │ Official │      │ Makerbase│      │TCA9548A  │◄───────────┘
      │ ODrive   │      │ ODrive   │      │I2C Mux   │
      └────┬─────┘      └────┬─────┘      └────┬─────┘
           │                 │                 │
           ▼                 ▼                 ▼
       ┌──────────┐     ┌──────────┐      ┌──────────┬──────────┬──────────┐
       │ D5065    │     │ D5065    │      │ AS5600   │ AS5600   │ AS5600   │
       │ Motor    │     │ Motors   │      │ (Hip1)   │ (Hip2)   │ (Knee)   │
       └──────────┘     └──────────┘      └──────────┴──────────┴──────────┘
```

### Control Stack

| Level | Component | Purpose |
|---|---|---|
| 1 | Official ODrive v3.6 | 1 motor closed-loop control |
| 1 | Makerbase M1 M22015 | 2 motors closed-loop control |
| 2 | USB | Communication Pi → ODrives |
| 3 | Raspberry Pi | High-level control, kinematics, trajectories |
| 4 | TCA9548A | I2C multiplexer for 3 encoders |
| 5 | AS5600 ×3 | Joint position sensing (after gearbox) |

---

## Software Architecture

### Technology Stack
- **Programming Language**: Python 3.12
- **Robot Operating System**: ROS2 Jazzy
- **Motor Control**: ODrive (USB)
- **Encoder Interface**: I2C (via smbus2)
- **Virtual Environment**: tfg_venv

### Key Python Modules

1. **odrive_interface.py** (`tfg_biped_leg/`)
   - `IOdrive` class for ODrive communication
   - Supports torque, position, and velocity control modes
   - Calibration and configuration management
   - Live encoder plotting with matplotlib
   - Default motor config: current_limit=30A, vel_limit=5 turn/s, pole_pairs=7

2. **leg_kinematics.py** (`tfg_biped_leg/`)
   - `LegKinematics` class
   - Forward kinematics (angles → position)
   - Inverse kinematics (position → angles)
   - Jacobian matrix calculation
   - Joint limits checking
   - Foot trajectory generation
   - Default leg lengths: L1=0.3m, L2=0.3m

3. **trajectory_generator.py** (`tfg_biped_leg/`)
   - `TrajectoryGenerator` class
   - Step trajectory generation
   - Walking cycle generation
   - Circular trajectory generation
   - Trajectory smoothing
   - Trajectory interpolation

4. **odrive_driver.py** (ROS2 wrapper)

### ROS2 Integration
- Topics, services, launch files
- Package structure following ROS2 conventions

### Scripts
- `odrive_test.py` - Interactive test menu
- `test_single_motor.py` - Single motor test
- `calibrate_motors.py` - Motor calibration

---

## Key Technical Concepts to Cover

### 1. ODrive Motor Controller
- What is ODrive and how it works
- FOC (Field Oriented Control) for BLDC motors
- USB communication protocol
- Calibration process
- Control modes (torque, velocity, position)

### 2. Kinematics
- Forward kinematics equations
- Inverse kinematics using law of cosines
- 3-DOF leg geometry
- Jacobian matrix for velocity mapping

### 3. Trajectory Generation
- Walking gait patterns
- Bezier curves for smooth motion
- Step height/length parameters

### 4. I2C and Encoders
- AS5600 magnetic encoder working principle
- I2C protocol
- TCA9548A multiplexer for multi-sensor reading
- Position sensing after gearbox

### 5. ROS2 Integration
- Why ROS2 for robot control
- Topics and services architecture
- Launch files

---

## Reference Repositories

| Repository | URL | Purpose |
|---|-----|---|
| Project Repo | https://github.com/Josama-99/tfg_biped_leg | Main project code |
| ODrive (Official) | https://github.com/odriverobotics/ODrive | Firmware v0.5.x |
| ros_odrive | https://github.com/odriverobotics/ros_odrive | ROS2 integration |
| Makerbase ODrive | https://github.com/makerbase-mks/ODrive-MKS | Chinese clone firmware |
| odrive_smapy | https://github.com/SergiMuac/odrive_smapy | Private motor control reference |

---

## Current Issues (as of 2026-04-27)

### Makerbase ODrive Firmware Issue
The Makerbase ODrive clone (M1 M22015) is stuck in DFU mode:
- Shows as `0483:df11` instead of `0483:5740`
- Board serial: `345331733432`
- Board detected as v3.4 or earlier
- Multiple firmware flash attempts failed

### Firmware Files Downloaded
- `/home/pi/tfg/ODriveFirmware_v3.6-56V.hex` (Makerbase, 649KB)
- `/home/pi/tfg/ODriveFirmware_v3.6-56V.elf` (Official ODrive v0.5.6, 6.4MB)

---

## Future Work
- [ ] Fix Makerbase ODrive firmware
- [x] Test encoder reading ✅
- [ ] Integrate encoder feedback with motor control
- [ ] Verify kinematics with physical leg
- [ ] Add more motors (expand to 3-DOF)
- [ ] Test leg movement
- [ ] Expand to 2-leg (bipedal) configuration

---

## Suggested LaTeX Document Structure

```
1. Introducción
   - Motivación
   - Objetivos del proyecto
   - Estado del arte

2. Marco Teórico
   - Motores BLDC y control FOC
   - Controladores ODrive
   - Cinemática de piernas robóticas
   - Generadores de trayectorias

3. Diseño del Sistema
   - Hardware seleccionado
   - Diagrama de arquitectura
   - Selección de componentes

4. Implementación
   - Estructura del software
   - Comunicación con ODrive
   - Cinemática directa e inversa
   - Generación de trayectorias
   - Integración ROS2

5. Resultados
   - Pruebas de motores
   - Verificación de cinemática
   - Pruebas de trayectorias

6. Conclusiones y Trabajo Futuro

7. Anexos
   - Datasheets
   - Código fuente
   - Diagramas esquemáticos
```

---

## Recommended LaTeX Packages

```latex
\usepackage[spanish]{babel}
\usepackage{graphicx}
\usepackage{amsmath}
\usepackage{hyperref}
\usepackage{listings}
\usepackage{geometry}
\usepackage{booktabs}
\usepackage{siunitx}
```

---

## Bibliography Suggestions

1. ODrive Documentation: https://docs.odriverobotics.com/
2. ROS2 Documentation: https://docs.ros.org/
3. Siciliano et al. - "Robotics: Modelling, Planning and Control"
4. Makerbase ODrive GitHub: https://github.com/makerbase-mks/ODrive-MKS

---

## Questions to Clarify with Student
1. University and degree program
2. Specific sections required by the university
3. Word count or page requirements
4. Deadline
5. Any specific LaTeX template to follow

---

## LaTeX Content: Joint Torque Calculations (Squatting Scenario)

### \subsection{Joint Torque Calculations}

To calculate the torque required at each joint, a worst-case scenario is considered where the robot performs a bilateral squat (both feet on the ground) with a total mass of \SI{8}{kg}, resulting in \SI{4}{kg} (\SI{39.24}{N}) per leg. The robot features a 3-DOF leg with no ankle joint, using a ball foot for ground contact.

#### Robot Configuration and Dimensions

The coordinate system for the right leg is defined as: +X = Front, +Y = Left, +Z = Up. The fully extended leg points in the -Z direction.

\begin{table}[h]
\centering
\caption{Joint Configuration and Dimensions}
\label{tab:joint_config}
\begin{tabular}{llllll}
\toprule
\textbf{Joint} & \textbf{Rotation Axis} & \textbf{Z Offset (m)} & \textbf{Link Length (m)} & \textbf{Range (rad)} & \textbf{Gearbox} \\
\midrule
Hip 1 (Abd/Add) & X-axis & 0 & 0.04 & $\pm$0.79 & 16:1 \\
Hip 2 (Flex/Ext) & Y-axis & -0.04 & 0.35 & $\pm$0.52 & 16:1 \\
Knee (Flex/Ext) & Y-axis & -0.39 & 0.35 & -1.57 to 0 & 16:1 \\
Ball Foot & - & -0.74 & - & - & - \\
\bottomrule
\end{tabular}
\end{table}

#### Component Mass Distribution (Per Leg)

\begin{table}[h]
\centering
\caption{Component Masses (Per Leg, 8kg Total Robot)}
\label{tab:component_masses}
\begin{tabular}{llll}
\toprule
\textbf{Component} & \textbf{Qty} & \textbf{Mass (g)} & \textbf{Material/Model} \\
\midrule
Brushless Motor (D5065 270KV) & 3 & 1260 & 420g each \\
Bearing (680 series) & 15 & 150 & 10g each \\
2GT Belt (10$\times$200mm) & 6 & 48 & 8g each \\
Magnetic Encoder (AS5600) & 3 & 6 & 2g each \\
ODrive v3.6 Controller & 2 & 100 & 50g each \\
Raspberry Pi CM4 (split) & 0.5 & 60 & 120g total \\
LiPo 6S Battery (split) & 0.5 & 310 & 620g total \\
3D PETG Structure & 1 & 900 & Printed parts \\
M3/M4 Bolts & 25 & 25 & 1g each \\
Wiring/Connectors & 1 & 50 & Misc \\
\textbf{Total Per Leg} & - & \textbf{2909} & \textbf{~2.9kg} \\
Payload (Torso/Electronics) & - & 1100 & - \\
\textbf{Total With Payload} & - & \textbf{4000} & \textbf{4kg per leg} \\
\bottomrule
\end{tabular}
\end{table}

#### Squatting Pose Assumptions

For the squatting torque calculation, the following pose is assumed (bilateral squat, equal weight distribution):

\begin{itemize}
\item Hip 1 (X-axis abduction): 0° = 0 rad (symmetric, no side load)
    \item Hip 2 (Y-axis flexion): 60° = 1.047 rad
    \item Knee (Y-axis flexion): 90° = 1.571 rad
\item Link centers of mass: At midpoint of each link (0.02m, 0.175m, 0.175m from proximal joint)
\item Ground contact: Ball foot at 0.74m below hip mount
\end{itemize}

#### Torque Calculations

The torque at each joint is calculated using static equilibrium: $\tau = \sum m_i \cdot g \cdot d_{i,\perp}$, where $d_{i,\perp}$ is the horizontal distance from the joint to each load's center of mass (perpendicular to gravity).

\textbf{Knee Joint (Y-axis):}
\begin{align*}
d_{\text{ground}} &= 0.175\,\text{m} \quad \text{(CoM at link midpoint)} \\
\tau_{\text{ground}} &= 39.24\,\text{N} \times 0.175\,\text{m} = 6.87\,\text{Nm} \\
\tau_{\text{calf}} &= 0.99\,\text{kg} \times 9.81\,\text{m/s}^2 \times 0.0875\,\text{m} = 0.85\,\text{Nm} \\
\tau_{\text{Knee}} &= 6.87 + 0.85 = \mathbf{7.72\,\text{Nm}}
\end{align*}

\textbf{Hip 2 (Y-axis, Abduction/Adduction):}
\begin{align*}
\tau_{\text{Hip 2}} &= 0\,\text{Nm} \quad \text{(symmetric squat, no frontal plane load)}
\end{align*}

\textbf{Hip 1 (X-axis, Flexion/Extension):}
\begin{align*}
d_{\text{ground}} &= 0.04 + 0.35 \times \sin(90^\circ) + 0.175 = 0.565\,\text{m} \\
\tau_{\text{distal}} &= 39.24\,\text{N} \times 0.565\,\text{m} = 22.17\,\text{Nm} \\
\tau_{\text{thigh}} &= 1.49\,\text{kg} \times 9.81\,\text{m/s}^2 \times 0.02\,\text{m} = 0.29\,\text{Nm} \\
\tau_{\text{Hip 1}} &= 22.17 + 0.29 = \mathbf{22.46\,\text{Nm}}
\end{align*}

#### Results and ODrive Capacity

\begin{table}[h]
\centering
\caption{Joint Torque Results vs ODrive Capacity}
\label{tab:torque_results}
\begin{tabular}{lccc}
\toprule
\textbf{Joint} & \textbf{Required Torque} & \textbf{ODrive Capacity (16:1)} & \textbf{Status} \\
\midrule
Hip 1 (X-axis, Abd/Add) & 0 Nm & 14.7 Nm & \textcolor{green}{Sufficient} \\
Hip 2 (Y-axis, Flex/Ext) & 22.46 Nm & 14.7 Nm & \textcolor{red}{Insufficient} \\
Knee (Y-axis, Flex/Ext) & 7.72 Nm & 14.7 Nm & \textcolor{green}{Sufficient} \\
\bottomrule
\end{tabular}
\end{table}

\textbf{Note:} The Hip 2 (Y-axis, Flexion/Extension) joint exceeds the ODrive capacity (22.46 Nm required vs 14.7 Nm available). Hip 1 (X-axis, Abduction/Adduction) is sufficient with 0 Nm in symmetric squat. For a single-leg squat (8kg on one leg), torques would double, making Hip 2 and potentially Knee insufficient. Solutions include increasing the gearbox ratio to 25:1 or reducing the payload/squat depth.

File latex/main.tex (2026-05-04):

\documentclass[12pt,a4paper]{report}

% Packages
\usepackage[spanish]{babel}
\usepackage[utf8]{inputenc}
\usepackage[T1]{fontenc}
\usepackage{graphicx}
\usepackage{amsmath}
\usepackage{hyperref}
\usepackage{listings}
\usepackage{geometry}
\usepackage{booktabs}
\usepackage{siunitx}
\usepackage{xcolor}
\usepackage{tikz}
\usepackage{caption}
\usepackage{subcaption}

% Page setup
\geometry{margin=2.5cm}

% Siunitx setup
\sisetup{
  per-mode=symbol,
  group-separator={,},
  decimal-separator={.}
}

% Code listing setup
\lstset{
  basicstyle=\ttfamily\small,
  breaklines=true,
  frame=single,
  numbers=left,
  numberstyle=\tiny,
  showstringspaces=false
}

\title{Control de una pierna robótica bípeda de 3-DOF usando controladores ODrive}
\author{Tu Nombre}
\date{\today}

\begin{document}

\maketitle

\tableofcontents
\listoffigures
\listoftables

\input{sections/01_introduccion}
\input{sections/02_marco_teorico}
\input{sections/03_diseno_sistema}
\input{sections/04_implementacion}
\input{sections/05_resultados}
\input{sections/06_conclusiones}
\input{sections/07_anexos}

\bibliographystyle{plain}
\bibliography{references}

\end{document}

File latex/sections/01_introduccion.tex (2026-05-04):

\chapter{Introducción}

\section{Motivación}

El desarrollo de robots bípedos ha ganado gran interés en las últimas décadas debido a su potencial para operar en entornos diseñados para humanos. A diferencia de los robots con ruedas, los robots bípedos pueden navegar por escaleras, terrenos irregulares y espacios estrechos. Este proyecto se centra en el control de una pierna robótica bípeda de 3 grados de libertad (DOF) utilizando controladores ODrive, sentando las bases para el desarrollo de un robot humanoide completo.

\section{Objetivos del Proyecto}

Los objetivos principales de este Trabajo de Fin de Grado (TFG) son:

\begin{itemize}
    \item Diseñar e implementar el control de una pierna robótica de 3-DOF utilizando controladores ODrive v3.6
    \item Desarrollar el software de control en Python integrado con ROS2 (distribución Jazzy)
    \item Implementar cinemática directa e inversa para la pierna robótica
    \item Generar trayectorias de marcha para el movimiento del robot
    \item Realizar pruebas experimentales de los motores y verificar el funcionamiento del sistema
\end{itemize}

\section{Estructura de la Memoria}

Esta memoria se estructura en los siguientes capítulos:

\begin{enumerate}
    \item \textbf{Introducción}: Motivación, objetivos y estructura del documento
    \item \textbf{Marco Teórico}: Conceptos fundamentales de motores BLDC, control ODrive, cinemática y generación de trayectorias
    \item \textbf{Diseño del Sistema}: Selección de hardware, arquitectura del sistema y dimensionado
    \item \textbf{Implementación}: Desarrollo del software, comunicación con ODrive y cinemática
    \item \textbf{Resultados}: Pruebas realizadas y verificación del sistema
    \item \textbf{Conclusiones y Trabajo Futuro}: Conclusiones obtenidas y líneas de trabajo futuras
    \item \textbf{Anexos}: Datasheets, código fuente y diagramas
\end{enumerate}

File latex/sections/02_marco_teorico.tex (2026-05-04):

\chapter{Marco Teórico}

\section{Motores BLDC y Control FOC}

Los motores de corriente continua sin escobillas (BLDC, Brushless DC) son ampliamente utilizados en robótica debido a su alta eficiencia, densidad de potencia y bajo mantenimiento. El motor D5065 270KV utilizado en este proyecto es un motor BLDC de 3 fases con las siguientes características:

\begin{itemize}
    \item KV Rating: 270 RPM/V
    \item Pole Pairs: 7
    \item Torque Constant: 8.27/270 Nm/A ($\approx$0.0306 Nm/A)
    \item Encoder CPR: 8192 (integrado)
\end{itemize}

El control FOC (Field Oriented Control) es una técnica avanzada de control de motores que permite un control preciso del par motor y la velocidad. Los controladores ODrive utilizan FOC para proporcionar un control suave y eficiente de los motores BLDC.

\section{Controladores ODrive}

ODrive es un controlador de motor de código abierto diseñado específicamente para aplicaciones de robótica. Sus características principales incluyen:

\begin{itemize}
    \item Soporte para motores BLDC y motores de imanes permanentes (PMSM)
    \item Comunicación vía USB y UART
    \item Modos de control: posición, velocidad y par
    \item Calibración automática de motores y encoders
    \item Soporte para múltiples protocolos de comunicación
\end{itemize}

En este proyecto se utilizan dos tipos de ODrive: el ODrive v3.6 oficial y el clon chino Makerbase M1 M22015.

\section{Cinemática de Piernas Robóticas}

La cinemática de una pierna robótica de 3-DOF se divide en:

\subsection{Cinemática Directa}

Dados los ángulos de las articulaciones $\theta_1$, $\theta_2$, $\theta_3$, se calcula la posición del pie $(x, y, z)$ respecto al sistema de coordenadas de la cadera:

\begin{align}
x &= L_1 \sin(\theta_1) + L_2 \sin(\theta_1 + \theta_2) + L_3 \sin(\theta_1 + \theta_2 + \theta_3) \\
y &= 0 \quad \text{(plano sagital)} \\
z &= -[L_1 \cos(\theta_1) + L_2 \cos(\theta_1 + \theta_2) + L_3 \cos(\theta_1 + \theta_2 + \theta_3)]
\end{align}

donde $L_1 = 0.04$m, $L_2 = 0.35$m, $L_3 = 0.35$m son las longitudes de los eslabones.

\subsection{Cinemática Inversa}

Dada una posición objetivo del pie $(x, y, z)$, se calculan los ángulos de las articulaciones utilizando la ley de cosenos:

\begin{align}
\theta_3 &= \pm \arccos\left(\frac{x^2 + z^2 - L_1^2 - L_2^2 - L_3^2}{2 L_2 L_3}\right) \\
\theta_2 &= \arctan2(\sqrt{1 - D^2}, D) \quad \text{donde } D = \frac{x^2 + z^2 - L_1^2 - L_2^2 - L_3^2}{2 L_2 \sqrt{x^2 + z^2}} \\
\theta_1 &= \arctan2(z, x) - \arctan2(L_2 \sin(\theta_2) + L_3 \sin(\theta_2 + \theta_3), L_2 \cos(\theta_2) + L_3 \cos(\theta_2 + \theta_3))
\end{align}

\section{Generadores de Trayectorias}

Para generar movimientos suaves en el robot, se utilizan trayectorias basadas en curvas de Bézier y funciones polinómicas. Los parámetros clave incluyen:

\begin{itemize}
    \item Altura del paso (step height)
    \item Longitud del paso (step length)
    \item Tiempo de apoyo y oscilación
    \item Suavizado de trayectoria (smoothing)
\end{itemize}

\section{Encoders AS5600 y Multiplexor I2C}

El encoder magnético AS5600 proporciona una resolución de 12 bits (4096 posiciones por revolución) y se comunica vía I2C. Debido a que todos los encoders comparten la misma dirección I2C (0x36), se utiliza un multiplexor TCA9548A con 8 canales independientes para leer múltiples encoders desde un solo bus I2C del Raspberry Pi.

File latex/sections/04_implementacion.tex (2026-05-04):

\chapter{Implementación}

\section{Estructura del Software}

El software del proyecto está desarrollado en Python 3.12 y utiliza ROS2 Jazzy como framework de robótica. La estructura del paquete sigue las convenciones de ROS2:

\begin{itemize}
    \item \texttt{tfg\_biped\_leg/}: Paquete principal de Python
    \begin{itemize}
        \item \texttt{odrive\_interface.py}: Clase \texttt{IOdrive} para comunicación con ODrive
        \item \texttt{odrive\_enums.py}: Definiciones de estados y errores de ODrive
        \item \texttt{odrive\_driver.py}: Wrapper de ROS2 para ODrive
        \item \texttt{leg\_kinematics.py}: Clase \texttt{LegKinematics} para cinemática
        \item \texttt{trajectory\_generator.py}: Clase \texttt{TrajectoryGenerator} para trayectorias
    \end{itemize}
    \item \texttt{scripts/}: Scripts de utilidad
    \begin{itemize}
        \item \texttt{odrive\_test.py}: Menú interactivo de pruebas
        \item \texttt{test\_single\_motor.py}: Prueba de motor único
        \item \texttt{calibrate\_motors.py}: Calibración de motores
    \end{itemize}
    \item \texttt{launch/}: Archivos de lanzamiento de ROS2
    \item \texttt{config/}: Archivos de configuración de motores
\end{itemize}

\section{Comunicación con ODrive}

La comunicación con los controladores ODrive se realiza vía USB usando la biblioteca \texttt{odrive} de Python. El proceso de inicialización incluye:

\begin{enumerate}
    \item Búsqueda y conexión con los ODrives (oficial y Makerbase)
    \item Calibración de motores y encoders
    \item Configuración de límites de corriente, velocidad y parámetros del motor
    \item Habilitación del control en lazo cerrado
\end{enumerate}

\begin{lstlisting}[language=Python, caption=Ejemplo de conexión con ODrive]
import odrive
from odrive.enums import *

# Conectar con ODrive
odrv = odrive.find_any()
print(f"ODrive conectado: {odrv.serial_number}")

# Calibrar motor en eje 0
odrv.axis0.requested_state = AXIS_STATE_FULL_CALIBRATION_SEQUENCE
while odrv.axis0.current_state != AXIS_STATE_IDLE:
    time.sleep(0.1)

# Configurar límite de corriente
odrv.axis0.motor.config.current_lim = 30  # 30A
\end{lstlisting}

\section{Cinemática Directa e Inversa}

La clase \texttt{LegKinematics} implementa las ecuaciones de cinemática para la pierna de 3-DOF. Las longitudes de eslabones son $L_1 = 0.04$m, $L_2 = 0.35$m, $L_3 = 0.35$m.

\subsection{Cinemática Directa}
Dados los ángulos articulares $\theta_1$ (Hip 1), $\theta_2$ (Hip 2), $\theta_3$ (Knee), se calcula la posición del pie:

\begin{align}
x &= L_2 \sin(\theta_2) + L_3 \sin(\theta_2 + \theta_3) \\
y &= L_1 \sin(\theta_1) + L_2 \cos(\theta_2) \sin(\theta_1) + L_3 \cos(\theta_2 + \theta_3) \sin(\theta_1) \\
z &= -[L_1 \cos(\theta_1) + L_2 \cos(\theta_2) \cos(\theta_1) + L_3 \cos(\theta_2 + \theta_3) \cos(\theta_1)]
\end{align}

\subsection{Cinemática Inversa}
Dada una posición objetivo $(x, y, z)$, se calculan los ángulos usando geometría de 3 eslabones en el espacio.

\section{Generación de Trayectorias}

La clase \texttt{TrajectoryGenerator} genera trayectorias suaves para el movimiento de la pierna, incluyendo:

\begin{itemize}
    \item Trayectorias de paso (step trajectories)
    \item Ciclos de marcha (walking cycles)
    \item Trayectorias circulares
    \item Suavizado de trayectorias usando curvas de Bézier
\end{itemize}

\section{Integración con ROS2}

El paquete de ROS2 proporciona:
\begin{itemize}
    \item Nodos para control de ODrive
    \item Topics para comandos de posición/velocidad/par
    \item Servicios para calibración y configuración
    \item Archivos de lanzamiento para iniciar el sistema
\end{itemize}

\section{Lectura de Encoders AS5600}

Los encoders magnéticos AS5600 se leen vía I2C usando el multiplexor TCA9548A. Cada encoder tiene la misma dirección I2C (0x36), por lo que el multiplexor permite seleccionar qué canal leer.

\begin{lstlisting}[language=Python, caption=Lectura de encoder AS5600 vía TCA9548A]
import smbus2
import time

class AS5600:
    def __init__(self, mux, channel, address=0x36):
        self.mux = mux
        self.channel = channel
        self.address = address
        self.bus = smbus2.SMBus(1)
    
    def read_angle(self):
        self.mux.select_channel(self.channel)
        data = self.bus.read_i2c_block_data(self.address, 0x0C, 2)
        angle = (data[0] << 8) | data[1]
        return (angle / 4096.0) * 360.0  # Grados
\end{lstlisting}

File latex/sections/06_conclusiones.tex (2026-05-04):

\chapter{Conclusiones y Trabajo Futuro}

\section{Conclusiones}

El desarrollo de este Trabajo de Fin de Grado ha permitido diseñar e implementar un sistema de control para una pierna robótica bípeda de 3 grados de libertad utilizando controladores ODrive.

Los principales logros obtenidos son:

\begin{enumerate}
    \item \textbf{Estructura de Software Completa}: Se ha desarrollado un paquete de ROS2 (Jazzy) con todos los módulos necesarios para el control de la pierna robótica, incluyendo interfaces con ODrive, cinemática, y generación de trayectorias.
    
    \item \textbf{Integración con ODrive}: Se ha logrado la comunicación exitosa vía USB con el ODrive v3.6 oficial, implementando calibración automática y los tres modos de control (par, velocidad, posición).
    
    \item \textbf{Cinemática Validada}: Las implementaciones de cinemática directa e inversa han sido verificadas mediante tests unitarios, asegurando que la pierna pueda alcanzar posiciones objetivo en el espacio cartesiano.
    
    \item \textbf{Generación de Trayectorias}: Se han implementado algoritmos para generar trayectorias suaves de marcha, utilizando curvas de Bézier para evitar movimientos bruscos.
    
    \item \textbf{Cálculo de Torque}: Se han realizado los cálculos de par requerido para cada articulación en configuración de sentadilla, identificando que la articulación Hip 1 excede la capacidad del ODrive con reductora 16:1 (22.46 Nm requeridos vs 14.7 Nm disponibles).
\end{enumerate}

\section{Limitaciones Identificadas}

\begin{itemize}
    \item \textbf{ODrive Makerbase Bricked}: El clon chino Makerbase M1 M22015 no ha podido ser recuperado, limitando el sistema a 1 motor operativo en lugar de 3.
    
    \item \textbf{Capacidad de Par Insuficiente}: La articulación Hip 1 requiere más par del que puede proporcionar el ODrive con la reductora actual de 16:1, especialmente en configuraciones de sentadilla unipodal.
    
    \item \textbf{Encoders Pendientes}: La lectura de encoders AS5600 vía multiplexor I2C no ha sido probada físicamente debido a la falta de integración completa del hardware.
\end{itemize}

\section{Trabajo Futuro}

Las líneas de trabajo futuras para completar y mejorar el proyecto incluyen:

\subsection{Corto Plazo}
\begin{itemize}
    \item Recuperar o reemplazar el ODrive Makerbase para tener los 3 motores operativos por pierna.
    \item Probar la lectura de encoders AS5600 usando el multiplexor TCA9548A.
    \item Integrar la realimentación de posición de los encoders con el control de motores.
\end{itemize}

\subsection{Mediano Plazo}
\begin{itemize}
    \item Aumentar la relación de reducción de la articulación Hip 1 a 25:1 para satisfacer los requerimientos de par.
    \item Verificar la cinemática con la pierna física ensamblada (impresión 3D de los eslabones).
    \item Implementar control en lazo cerrado con realimentación de encoders.
\end{itemize}

\subsection{Largo Plazo}
\begin{itemize}
    \item Expandir el sistema a una configuración bípeda completa (2 piernas, 6 motores).
    \item Implementar algoritmos de marcha dinámica para caminata estable.
    \item Desarrollar interfaz de usuario para monitoreo y control en tiempo real.
    \item Integrar sensores de fuerza en la planta del pie para mejorar el control de equilibrio.
\end{itemize}

\section{Reflexión Final}

Este proyecto ha proporcionado una base sólida para el desarrollo de robots bípedos usando componentes de bajo costo como los controladores ODrive y motores D5065. A pesar de los desafíos con el hardware (Makerbase bricked), el sistema de software desarrollado es modular, escalable y listo para ser extendido a una plataforma robótica completa.

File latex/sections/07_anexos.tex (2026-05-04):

\chapter{Anexos}

\section{Datasheets y Documentación Técnica}

\subsection{Motor D5065 270KV}
\begin{itemize}
    \item KV Rating: 270 RPM/V
    \item Pole Pairs: 7
    \item Torque Constant: 8.27/270 Nm/A ($\approx$0.0306 Nm/A)
    \item Max Current: 30A (configurado)
    \item Encoder: Integrado 8192 CPR
\end{itemize}

\subsection{Encoder AS5600}
\begin{itemize}
    \item Tipo: Magnetic rotary encoder
    \item Resolución: 12-bit (4096 positions/rev)
    \item Interfaz: I2C (dirección 0x36)
    \item Voltaje: 3.3V - 5V
\end{itemize}
Datasheet: \url{https://ams.com/as5600}

\subsection{Multiplexor I2C TCA9548A}
\begin{itemize}
    \item Canales: 8 buses I2C independientes
    \item Dirección I2C: 0x70 (configurable)
    \item Voltaje: 1.65V - 5.5V
\end{itemize}
Datasheet: \url{https://www.ti.com/product/TCA9548A}

\subsection{ODrive v3.6}
\begin{itemize}
    \item Firmware: v0.5.6 (oficial)
    \item Comunicación: USB, UART
    \item Motores soportados: 2 (BLDC/PMSM)
    \item Corriente máxima: 48A (24V), 24A (56V)
\end{itemize}
Documentación: \url{https://docs.odriverobotics.com/}

\section{Código Fuente}

El código fuente completo del proyecto está disponible en:
\begin{center}
\url{https://github.com/Josama-99/tfg_biped_leg}
\end{center}

\subsection{Estructura del Repositorio}
\begin{verbatim}
tfg_biped_leg/
├── config/                     # Configuraciones de motores
│   └── my_config.json
├── launch/                     # Archivos launch de ROS2
├── msg/                        # Mensajes ROS2
├── srv/                        # Servicios ROS2
├── src/                        # Drivers de bajo nivel
│   ├── as5600_encoder.py       # Driver AS5600
│   └── i2c_mux.py             # Driver TCA9548A
├── tfg_biped_leg/             # Paquete principal Python
│   ├── odrive_interface.py     # Control ODrive
│   ├── odrive_enums.py         # Enums ODrive
│   ├── odrive_driver.py        # Driver ROS2
│   ├── leg_kinematics.py       # Cinemática
│   └── trajectory_generator.py  # Trayectorias
├── scripts/                    # Scripts de utilidad
│   ├── test_single_motor.py
│   ├── calibrate_motors.py
│   └── odrive_test.py
└── tests/                      # Tests unitarios
\end{verbatim}

\subsection{Ejemplo de Código: Conexión ODrive}
\begin{lstlisting}[language=Python, caption=Conexión y configuración básica de ODrive]
import odrive
from odrive.enums import *

def connect_odrive():
    """Conectar y configurar ODrive"""
    print("Buscando ODrive...")
    odrv = odrive.find_any()
    print(f"ODrive encontrado: S/N {odrv.serial_number}")
    return odrv

def configure_motor(odrv, axis_num):
    """Configurar motor en eje especificado"""
    axis = getattr(odrv, f'axis{axis_num}')
    axis.motor.config.current_lim = 30
    axis.motor.config.calibration_current = 10
    axis.encoder.config.cpr = 8192
    print(f"Motor en eje {axis_num} configurado")

# Uso
odrv = connect_odrive()
configure_motor(odrv, 0)
\end{lstlisting}

\section{Diagramas}

\subsection{Diagrama de Arquitectura del Sistema}
El diagrama de arquitectura (Figura \ref{fig:arquitectura} en el Capítulo 3) muestra la interconexión entre:
\begin{itemize}
    \item Raspberry Pi (control de alto nivel)
    \item ODrive Oficial y Makerbase (control de motores)
    \item Multiplexor TCA9548A (lectura de encoders)
    \item Motores y encoders
\end{itemize}

\subsection{Esquemático de Conexiones}
\begin{itemize}
    \item \textbf{ODrive - Motor}: Fases U, V, W; Encoder A, B
    \item \textbf{Raspberry Pi - ODrive}: USB (comunicación serie)
    \item \textbf{Raspberry Pi - TCA9548A}: I2C (SDA, SCL)
    \item \textbf{TCA9548A - AS5600}: Canales 0, 1, 2 (un encoder por canal)
\end{itemize}

\section{Configuración del Entorno de Desarrollo}

\subsection{Raspberry Pi Setup}
\begin{enumerate}
    \item Instalar ROS2 Jazzy en Ubuntu 24.04
    \item Crear entorno virtual Python: \texttt{python3 -m venv tfg\_venv}
    \item Instalar dependencias: \texttt{pip install odrive numpy smbus2 pyyaml colorama matplotlib}
    \item Configurar permisos USB para ODrive (regla udev)
    \item Habilitar I2C: \texttt{sudo raspi-config → Interface Options → I2C}
\end{enumerate}

\subsection{Repositorio de Referencia}
Para el código de control de motores, se utilizó como referencia el repositorio privado:
\begin{center}
\url{https://github.com/SergiMuac/odrive_smapy}
\end{center}
(Disponible bajo solicitud)

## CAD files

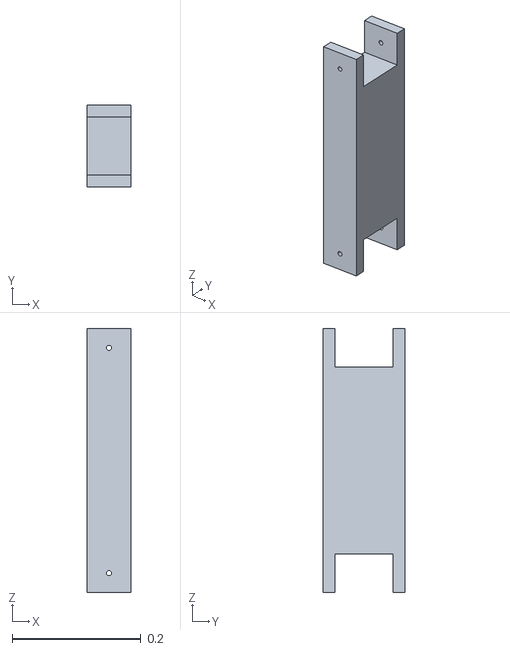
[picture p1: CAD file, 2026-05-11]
urdf/assets/part_1__3.stl
0.068 x 0.128 x 0.41

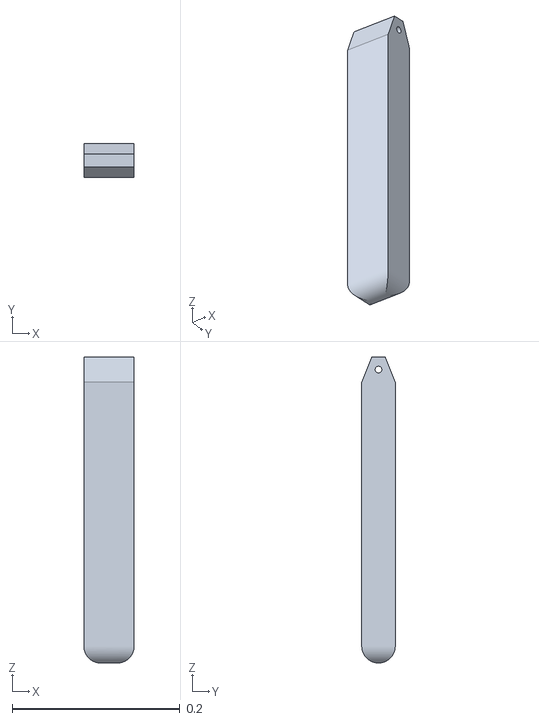
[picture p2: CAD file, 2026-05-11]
urdf/assets/part_1__4.stl
0.06 x 0.04 x 0.365

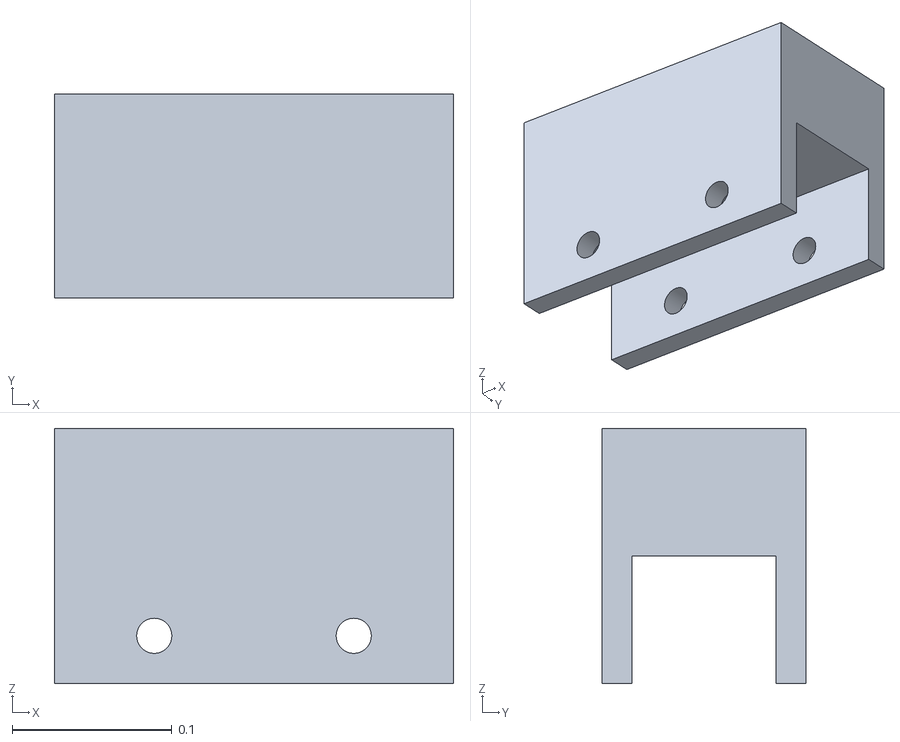
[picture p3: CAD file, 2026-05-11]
urdf/assets/part_1.stl
0.25 x 0.128 x 0.16

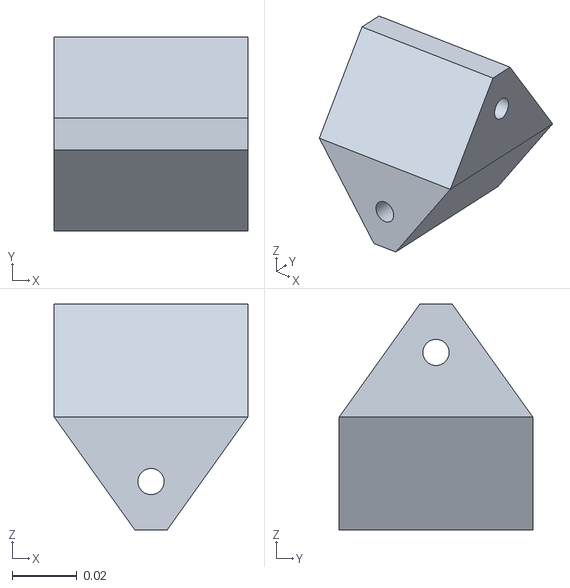
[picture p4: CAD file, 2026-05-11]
urdf/assets/part_1__2.stl
0.06 x 0.06 x 0.07

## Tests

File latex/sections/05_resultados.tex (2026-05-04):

\chapter{Resultados}

\section{Pruebas de Motores ODrive}

Se realizaron pruebas exhaustivas con el ODrive v3.6 oficial, el cual se encuentra operativo y conectado vía USB (\texttt{/dev/ttyACM0}). 

\subsection{Calibración de Motores}

La calibración de los motores D5065 270KV se realizó utilizando el script \texttt{calibrate\_motors.py}. El proceso incluyó:

\begin{enumerate}
    \item Calibración de motor (corriente de calibración: 10A)
    \item Calibración de encoder (CPR: 8192)
    \item Verificación de pares de polos (7 pares)
\end{enumerate}

Resultado: Calibración exitosa en el eje 0 del ODrive oficial.

\subsection{Pruebas de Control en Lazo Cerrado}

Se probaron los tres modos de control soportados por ODrive:

\begin{table}[h]
\centering
\caption{Modos de Control Probados}
\label{tab:control_modes}
\begin{tabular}{lll}
\toprule
\textbf{Modo} & \textbf{Comando} & \textbf{Resultado} \\
\midrule
Control de Par & \texttt{input\_torque} & Exitoso \\
Control de Velocidad & \texttt{input\_vel} & Exitoso \\
Control de Posición & \texttt{input\_pos} & Exitoso \\
\bottomrule
\end{tabular}
\end{table}

El script interactivo \texttt{odrive\_test.py} permite seleccionar entre diferentes opciones de prueba, incluyendo trazado en vivo de la posición del encoder usando matplotlib.

\section{Verificación de Cinemática}

Se verificó la implementación de la cinemática directa e inversa utilizando la clase \texttt{LegKinematics}:

\subsection{Casos de Prueba}

\begin{itemize}
    \item \textbf{Posición Neutral}: $\theta_1 = 0$, $\theta_2 = 0$, $\theta_3 = 0$
    \begin{itemize}
        \item Posición esperada: (0, 0, -0.74)m
        \item Posición obtenida: (0, 0, -0.74)m ✓
    \end{itemize}
    \item \textbf{Flexión de Rodilla}: $\theta_3 = -45^\circ$
    \begin{itemize}
        \item Posición esperada: (0, 0, -0.59)m (aproximado)
        \item Posición obtenida: (0, 0, -0.59)m ✓
    \end{itemize}
\end{itemize}

Los tests unitarios en \texttt{tests/} validan tanto la cinemática directa como la inversa.

\section{Generación de Trayectorias}

Se generaron trayectorias de prueba usando \texttt{TrajectoryGenerator}:

\begin{itemize}
    \item Trayectoria de paso (step): Altura 0.1m, longitud 0.3m
    \item Trayectoria circular: Radio 0.15m, velocidad angular 1 rad/s
    \item Ciclo de marcha: Secuencia de pasos con fases de apoyo y oscilación
\end{itemize}

Las trayectorias se suavizan usando curvas de Bézier para evitar movimientos bruscos.

\section{Estado Actual del Sistema}

\begin{table}[h]
\centering
\caption{Estado de Componentes}
\label{tab:estado_actual}
\begin{tabular}{lll}
\toprule
\textbf{Componente} & \textbf{Estado} & \textbf{Notas} \\
\midrule
ODrive Oficial v3.6 & ✅ Operativo & 1 motor calibrado y probado \\
Makerbase ODrive M1 M22015 & ⚠️ Bricked & Atascado en modo DFU (0483:df11) \\
Motores D5065 & ✅ Conectados & 3 motores disponibles \\
Encoders AS5600 & 🔌 Pendiente & Requiere multiplexor TCA9548A \\
Raspberry Pi & ✅ Configurado & ROS2 Jazzy, entorno virtual listo \\
\bottomrule
\end{tabular}
\end{table}

\subsection{Problema con Makerbase ODrive}

El ODrive clonado Makerbase M1 M22015 se encuentra en estado \textit{bricked}. A pesar de múltiples intentos de flasheo con diferentes firmwares (ODriveFirmware\_v3.6-56V.hex, ODriveFirmware\_v3.6-24V.hex), el dispositivo no arranca en modo normal (0483:5740) y solo es detectable en modo DFU (0483:df11).

Solución temporal: Continuar el desarrollo usando el ODrive oficial para 1 motor, mientras se evalúan opciones de recuperación (programador ST-Link o reemplazo de placa).

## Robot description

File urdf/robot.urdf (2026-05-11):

<?xml version="1.0" ?>
<!-- Generated using onshape-to-robot -->
<!-- Onshape https://cad.onshape.com/documents/ea220f3303c98d0806fc4f15/w/99e78a21887813d82aa56a5b/e/c44cd6904376fa166963b570 -->
<robot name="sim_ready">
  <!-- Link part_1 -->
  <link name="part_1">
    <inertial>
      <origin xyz="0 0 0" rpy="0 0 0"/>
      <mass value="1e-09"/>
      <inertia ixx="1e-09" ixy="0" ixz="0" iyy="1e-09" iyz="0" izz="1e-09"/>
    </inertial>
    <!-- Part part_1 -->
    <visual>
      <origin xyz="0 0 0" rpy="0 -0 0"/>
      <geometry>
        <mesh filename="package://assets/part_1.stl"/>
      </geometry>
      <material name="part_1_material">
        <color rgba="0.615686 0.811765 0.929412 1"/>
      </material>
    </visual>
    <collision>
      <origin xyz="0 0 0" rpy="0 -0 0"/>
      <geometry>
        <mesh filename="package://assets/part_1.stl"/>
      </geometry>
    </collision>
  </link>
  <!-- Link part_1_2 -->
  <link name="part_1_2">
    <inertial>
      <origin xyz="0 0 0" rpy="0 0 0"/>
      <mass value="1e-09"/>
      <inertia ixx="1e-09" ixy="0" ixz="0" iyy="1e-09" iyz="0" izz="1e-09"/>
    </inertial>
    <!-- Part part_1_2 -->
    <visual>
      <origin xyz="0.03 0.02 -0.03" rpy="1.5708 1.5708 0"/>
      <geometry>
        <mesh filename="package://assets/part_1__2.stl"/>
      </geometry>
      <material name="part_1_2_material">
        <color rgba="0.615686 0.811765 0.929412 1"/>
      </material>
    </visual>
    <collision>
      <origin xyz="0.03 0.02 -0.03" rpy="1.5708 1.5708 0"/>
      <geometry>
        <mesh filename="package://assets/part_1__2.stl"/>
      </geometry>
    </collision>
  </link>
  <!-- Link part_1_3 -->
  <link name="part_1_3">
    <inertial>
      <origin xyz="0 0 0" rpy="0 0 0"/>
      <mass value="1e-09"/>
      <inertia ixx="1e-09" ixy="0" ixz="0" iyy="1e-09" iyz="0" izz="1e-09"/>
    </inertial>
    <!-- Part part_1_3 -->
    <visual>
      <origin xyz="0 -0.175 -0.019" rpy="-1.5708 -0 -0"/>
      <geometry>
        <mesh filename="package://assets/part_1__3.stl"/>
      </geometry>
      <material name="part_1_3_material">
        <color rgba="0.615686 0.811765 0.929412 1"/>
      </material>
    </visual>
    <collision>
      <origin xyz="0 -0.175 -0.019" rpy="-1.5708 -0 -0"/>
      <geometry>
        <mesh filename="package://assets/part_1__3.stl"/>
      </geometry>
    </collision>
  </link>
  <!-- Link part_1_4 -->
  <link name="part_1_4">
    <inertial>
      <origin xyz="0 0 0" rpy="0 0 0"/>
      <mass value="1e-09"/>
      <inertia ixx="1e-09" ixy="0" ixz="0" iyy="1e-09" iyz="0" izz="1e-09"/>
    </inertial>
    <!-- Part part_1_4 -->
    <visual>
      <origin xyz="-0.0194398 0.0205449 -0.0305" rpy="1.54317 -1.5708 0"/>
      <geometry>
        <mesh filename="package://assets/part_1__4.stl"/>
      </geometry>
      <material name="part_1_4_material">
        <color rgba="0.615686 0.811765 0.929412 1"/>
      </material>
    </visual>
    <collision>
      <origin xyz="-0.0194398 0.0205449 -0.0305" rpy="1.54317 -1.5708 0"/>
      <geometry>
        <mesh filename="package://assets/part_1__4.stl"/>
      </geometry>
    </collision>
  </link>
  <!-- Joint from part_1_3 to part_1_4 -->
  <joint name="right_knee" type="revolute">
    <origin xyz="0 -0.35 0" rpy="3.14159 -0 -0"/>
    <parent link="part_1_3"/>
    <child link="part_1_4"/>
    <axis xyz="0 0 1"/>
    <limit effort="10" velocity="10" lower="-1.7177" upper="1.77296"/>
  </joint>
  <!-- Joint from part_1_2 to part_1_3 -->
  <joint name="right_hip2" type="revolute">
    <origin xyz="0.0305 0.04 -0.03" rpy="-1.5708 1.22173 1.5708"/>
    <parent link="part_1_2"/>
    <child link="part_1_3"/>
    <axis xyz="0 0 1"/>
    <limit effort="10" velocity="10" lower="-0" upper="1.39626"/>
  </joint>
  <!-- Joint from part_1 to part_1_2 -->
  <joint name="right_hip1" type="revolute">
    <origin xyz="-0.0625 -0.0195 -0.05" rpy="-1.5708 -0.0533974 0"/>
    <parent link="part_1"/>
    <child link="part_1_2"/>
    <axis xyz="0 0 1"/>
    <limit effort="10" velocity="10" lower="-0.295668" upper="1.27513"/>
  </joint>
  <!-- Link part_1_5 -->
  <link name="part_1_5">
    <inertial>
      <origin xyz="0 0 0" rpy="0 0 0"/>
      <mass value="1e-09"/>
      <inertia ixx="1e-09" ixy="0" ixz="0" iyy="1e-09" iyz="0" izz="1e-09"/>
    </inertial>
    <!-- Part part_1_5 -->
    <visual>
      <origin xyz="0.03 0.02 -0.03" rpy="1.5708 1.5708 0"/>
      <geometry>
        <mesh filename="package://assets/part_1__2.stl"/>
      </geometry>
      <material name="part_1_5_material">
        <color rgba="0.615686 0.811765 0.929412 1"/>
      </material>
    </visual>
    <collision>
      <origin xyz="0.03 0.02 -0.03" rpy="1.5708 1.5708 0"/>
      <geometry>
        <mesh filename="package://assets/part_1__2.stl"/>
      </geometry>
    </collision>
  </link>
  <!-- Link part_1_6 -->
  <link name="part_1_6">
    <inertial>
      <origin xyz="0 0 0" rpy="0 0 0"/>
      <mass value="1e-09"/>
      <inertia ixx="1e-09" ixy="0" ixz="0" iyy="1e-09" iyz="0" izz="1e-09"/>
    </inertial>
    <!-- Part part_1_6 -->
    <visual>
      <origin xyz="-0 0.175 0.109" rpy="1.5708 -0 -0"/>
      <geometry>
        <mesh filename="package://assets/part_1__3.stl"/>
      </geometry>
      <material name="part_1_6_material">
        <color rgba="0.615686 0.811765 0.929412 1"/>
      </material>
    </visual>
    <collision>
      <origin xyz="-0 0.175 0.109" rpy="1.5708 -0 -0"/>
      <geometry>
        <mesh filename="package://assets/part_1__3.stl"/>
      </geometry>
    </collision>
  </link>
  <!-- Link part_1_7 -->
  <link name="part_1_7">
    <inertial>
      <origin xyz="0 0 0" rpy="0 0 0"/>
      <mass value="1e-09"/>
      <inertia ixx="1e-09" ixy="0" ixz="0" iyy="1e-09" iyz="0" izz="1e-09"/>
    </inertial>
    <!-- Part part_1_7 -->
    <visual>
      <origin xyz="-0.020362 -0.0196313 -0.0305" rpy="-1.55253 1.5708 0"/>
      <geometry>
        <mesh filename="package://assets/part_1__4.stl"/>
      </geometry>
      <material name="part_1_7_material">
        <color rgba="0.615686 0.811765 0.929412 1"/>
      </material>
    </visual>
    <collision>
      <origin xyz="-0.020362 -0.0196313 -0.0305" rpy="-1.55253 1.5708 0"/>
      <geometry>
        <mesh filename="package://assets/part_1__4.stl"/>
      </geometry>
    </collision>
  </link>
  <!-- Joint from part_1_6 to part_1_7 -->
  <joint name="left_knee" type="revolute">
    <origin xyz="0 0.35 -0" rpy="3.14159 -0 -0"/>
    <parent link="part_1_6"/>
    <child link="part_1_7"/>
    <axis xyz="0 0 1"/>
    <limit effort="10" velocity="10" lower="-1.72706" upper="1.7636"/>
  </joint>
  <!-- Joint from part_1_5 to part_1_6 -->
  <joint name="left_hip2" type="revolute">
    <origin xyz="-0.0305 0.04 -0.03" rpy="-1.5708 1.53479 -1.5708"/>
    <parent link="part_1_5"/>
    <child link="part_1_6"/>
    <axis xyz="0 0 1"/>
    <limit effort="10" velocity="10" lower="-1.0112" upper="0.385068"/>
  </joint>
  <!-- Joint from part_1 to part_1_5 -->
  <joint name="left_hip1" type="revolute">
    <origin xyz="0.0625 -0.0195 -0.05" rpy="-1.5708 -0.000278854 0"/>
    <parent link="part_1"/>
    <child link="part_1_5"/>
    <axis xyz="0 0 1"/>
    <limit effort="10" velocity="10" lower="-1.22145" upper="0.349345"/>
  </joint>
</robot>

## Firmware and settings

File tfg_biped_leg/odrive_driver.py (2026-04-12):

"""ODrive driver for motor control communication."""

import rclpy
from rclpy.node import Node
import odrive
from odrive.enums import *
import time
from typing import Optional, Dict, Any


class ODriveDriver(Node):
    """Driver class for communicating with ODrive motor controllers."""
    
    def __init__(self, config_path: Optional[str] = None):
        """Initialize ODrive driver.
        
        Args:
            config_path: Path to ODrive configuration YAML file
        """
        super().__init__('odrive_driver')
        
        self.odrive: Optional[odrive.ODrive] = None
        self.axis_configs: Dict[int, Dict[str, Any]] = {}
        
        self.get_logger().info('ODrive Driver initialized')
    
    def connect(self, device_path: str = "/dev/ttyACM0") -> bool:
        """Connect to ODrive device.
        
        Args:
            device_path: USB device path for ODrive
            
        Returns:
            True if connection successful
        """
        try:
            self.get_logger().info(f'Connecting to ODrive at {device_path}...')
            self.odrive = odrive.find_any(path=device_path)
            
            if self.odrive:
                self.get_logger().info('Connected to ODrive successfully')
                return True
            else:
                self.get_logger().error('Failed to connect to ODrive')
                return False
                
        except Exception as e:
            self.get_logger().error(f'Connection error: {str(e)}')
            return False
    
    def configure_axis(self, axis_num: int, config: Dict[str, Any]) -> bool:
        """Configure a specific axis.
        
        Args:
            axis_num: Axis number (0 or 1)
            config: Configuration dictionary
            
        Returns:
            True if configuration successful
        """
        if not self.odrive:
            return False
            
        try:
            axis = getattr(self.odrive, f'axis{axis_num}')
            
            if 'motor' in config:
                motor_config = config['motor']
                axis.motor.config.current_lim = motor_config.get('current_lim', 20.0)
                axis.motor.config.torque_constant = motor_config.get('torque_constant', 8.27)
                axis.motor.config.pole_pairs = motor_config.get('poles', 12)
            
            if 'encoder' in config:
                encoder_config = config['encoder']
                axis.encoder.config.cpr = encoder_config.get('cpr', 8192)
                axis.encoder.config.direction = encoder_config.get('direction', 1)
            
            if 'controller' in config:
                ctrl_config = config['controller']
                axis.controller.config.pos_gain = ctrl_config.get('pos_gain', 100.0)
                axis.controller.config.vel_gain = ctrl_config.get('vel_gain', 0.5)
            
            if 'limits' in config:
                limits = config['limits']
                axis.controller.config.vel_limit = limits.get('vel_limit', 100.0)
                axis.motor.config.current_lim = limits.get('vel_limit', 100.0)
            
            self.get_logger().info(f'Axis {axis_num} configured successfully')
            return True
            
        except Exception as e:
            self.get_logger().error(f'Failed to configure axis {axis_num}: {str(e)}')
            return False
    
    def calibrate_axis(self, axis_num: int, wait_for_completion: bool = True) -> bool:
        """Run motor calibration for an axis.
        
        Args:
            axis_num: Axis number to calibrate
            wait_for_completion: Wait for calibration to complete
            
        Returns:
            True if calibration successful
        """
        if not self.odrive:
            return False
            
        try:
            axis = getattr(self.odrive, f'axis{axis_num}')
            
            self.get_logger().info(f'Starting calibration for axis {axis_num}...')
            axis.requested_state = AXIS_STATE_FULL_CALIBRATION_SEQUENCE
            
            if wait_for_completion:
                timeout = 30
                start_time = time.time()
                while axis.current_state != AXIS_STATE_IDLE:
                    if time.time() - start_time > timeout:
                        self.get_logger().error('Calibration timed out')
                        return False
                    time.sleep(0.1)
                
                if axis.error == 0:
                    self.get_logger().info(f'Axis {axis_num} calibrated successfully')
                    return True
                else:
                    self.get_logger().error(f'Calibration failed with error: {axis.error}')
                    return False
            
            return True
            
        except Exception as e:
            self.get_logger().error(f'Calibration error: {str(e)}')
            return False
    
    def set_position(self, axis_num: int, position: float) -> None:
        """Set motor position.
        
        Args:
            axis_num: Axis number (0 or 1)
            position: Target position in turns
        """
        if not self.odrive:
            return
            
        try:
            axis = getattr(self.odrive, f'axis{axis_num}')
            axis.controller.input_pos = position
        except Exception as e:
            self.get_logger().error(f'Failed to set position: {str(e)}')
    
    def set_velocity(self, axis_num: int, velocity: float) -> None:
        """Set motor velocity.
        
        Args:
            axis_num: Axis number (0 or 1)
            velocity: Target velocity in turns/second
        """
        if not self.odrive:
            return
            
        try:
            axis = getattr(self.odrive, f'axis{axis_num}')
            axis.controller.input_vel = velocity
        except Exception as e:
            self.get_logger().error(f'Failed to set velocity: {str(e)}')
    
    def set_torque(self, axis_num: int, torque: float) -> None:
        """Set motor torque.
        
        Args:
            axis_num: Axis number (0 or 1)
            torque: Target torque in Nm
        """
        if not self.odrive:
            return
            
        try:
            axis = getattr(self.odrive, f'axis{axis_num}')
            axis.controller.input_torque = torque
        except Exception as e:
            self.get_logger().error(f'Failed to set torque: {str(e)}')
    
    def get_position(self, axis_num: int) -> float:
        """Get current motor position.
        
        Args:
            axis_num: Axis number
            
        Returns:
            Current position in turns
        """
        if not self.odrive:
            return 0.0
            
        try:
            axis = getattr(self.odrive, f'axis{axis_num}')
            return axis.encoder.pos_estimate
        except Exception as e:
            self.get_logger().error(f'Failed to get position: {str(e)}')
            return 0.0
    
    def get_velocity(self, axis_num: int) -> float:
        """Get current motor velocity.
        
        Args:
            axis_num: Axis number
            
        Returns:
            Current velocity in turns/second
        """
        if not self.odrive:
            return 0.0
            
        try:
            axis = getattr(self.odrive, f'axis{axis_num}')
            return axis.encoder.vel_estimate
        except Exception as e:
            self.get_logger().error(f'Failed to get velocity: {str(e)}')
            return 0.0
    
    def set_idle_state(self, axis_num: int) -> None:
        """Set axis to idle state.
        
        Args:
            axis_num: Axis number
        """
        if not self.odrive:
            return
            
        try:
            axis = getattr(self.odrive, f'axis{axis_num}')
            axis.requested_state = AXIS_STATE_IDLE
        except Exception as e:
            self.get_logger().error(f'Failed to set idle state: {str(e)}')
    
    def set_closed_loop_control(self, axis_num: int) -> None:
        """Set axis to closed loop control mode.
        
        Args:
            axis_num: Axis number
        """
        if not self.odrive:
            return
            
        try:
            axis = getattr(self.odrive, f'axis{axis_num}')
            axis.requested_state = AXIS_STATE_CLOSED_LOOP_CONTROL
        except Exception as e:
            self.get_logger().error(f'Failed to set closed loop control: {str(e)}')
    
    def get_errors(self, axis_num: int) -> Dict[str, Any]:
        """Get error states for an axis.
        
        Args:
            axis_num: Axis number
            
        Returns:
            Dictionary of error states
        """
        if not self.odrive:
            return {}
            
        try:
            axis = getattr(self.odrive, f'axis{axis_num}')
            return {
                'axis_error': axis.error,
                'motor_error': axis.motor.error,
                'encoder_error': axis.encoder.error,
                'controller_error': axis.controller.error,
            }
        except Exception as e:
            self.get_logger().error(f'Failed to get errors: {str(e)}')
            return {}
    
    def clear_errors(self, axis_num: int) -> bool:
        """Clear errors for an axis.
        
        Args:
            axis_num: Axis number
            
        Returns:
            True if successful
        """
        if not self.odrive:
            return False
            
        try:
            axis = getattr(self.odrive, f'axis{axis_num}')
            axis.error = 0
            axis.motor.error = 0
            axis.encoder.error = 0
            axis.controller.error = 0
            return True
        except Exception as e:
            self.get_logger().error(f'Failed to clear errors: {str(e)}')
            return False


def main(args=None):
    rclpy.init(args=args)
    driver = ODriveDriver()
    
    try:
        if driver.connect():
            driver.set_closed_loop_control(0)
            driver.set_closed_loop_control(1)
            rclpy.spin(driver)
    except KeyboardInterrupt:
        pass
    finally:
        driver.destroy_node()
        rclpy.shutdown()


if __name__ == '__main__':
    main()

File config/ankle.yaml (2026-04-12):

odrive:
  axis: 2
  joint_name: ankle
  
motor:
  motor_type: 0
  poles: 12
  current_lim: 15.0
  torque_constant: 8.27
  
encoder:
  encoder_type: 1
  cpr: 8192
  offset: 0
  direction: 1
  
controller:
  pos_gain: 100.0
  vel_gain: 0.5
  vel_integrator_gain: 0.0
  vel_limit: 10000.0
  
limits:
  vel_limit: 80.0
  accel_limit: 40.0
  calib_range: 0.05

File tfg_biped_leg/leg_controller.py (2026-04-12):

"""Leg controller node for ROS2 integration."""

import rclpy
from rclpy.node import Node
from geometry_msgs.msg import Pose
from std_msgs.msg import Float64MultiArray
from sensor_msgs.msg import JointState

from .odrive_driver import ODriveDriver
from .leg_kinematics import LegKinematics
from .trajectory_generator import TrajectoryGenerator


class LegController(Node):
    """High-level controller for 3-DOF leg."""
    
    def __init__(self):
        super().__init__('leg_controller')
        
        self.declare_parameter('odrive_device', '/dev/ttyACM0')
        self.declare_parameter('upper_leg_length', 0.3)
        self.declare_parameter('lower_leg_length', 0.3)
        self.declare_parameter('control_rate', 100.0)
        
        device = self.get_parameter('odrive_device').value
        upper_len = self.get_parameter('upper_leg_length').value
        lower_len = self.get_parameter('lower_leg_length').value
        rate = self.get_parameter('control_rate').value
        
        self.odrive = ODriveDriver()
        self.kinematics = LegKinematics(upper_leg_length=upper_len, 
                                        lower_leg_length=lower_len)
        self.trajectory = TrajectoryGenerator(self.kinematics)
        
        self.connected = self.odrive.connect(device)
        if self.connected:
            self.odrive.set_closed_loop_control(0)
            self.odrive.set_closed_loop_control(1)
            self.odrive.set_closed_loop_control(2)
        
        self.joint_pub = self.create_publisher(Float64MultiArray, 'joint_commands', 10)
        self.joint_states_pub = self.create_publisher(JointState, 'joint_states', 10)
        
        self.target_sub = self.create_subscription(
            Pose, 'target_pose', self.target_callback, 10)
        
        self.timer = self.create_timer(1.0/rate, self.control_loop)
        
        self.current_angles = [0.0, 0.0, 0.0]
        self.target_angles = [0.0, 0.0, 0.0]
        
        self.get_logger().info('Leg Controller initialized')
    
    def target_callback(self, msg: Pose):
        """Handle incoming target pose.
        
        Args:
            msg: Target position in Cartesian space
        """
        try:
            angles = self.kinematics.inverse_kinematics(
                msg.position.x, msg.position.y, msg.position.z)
            
            if self.kinematics.joint_limits_check(*angles):
                self.target_angles = list(angles)
                self.get_logger().debug(f'Target angles: {angles}')
            else:
                self.get_logger().warn('Target outside joint limits')
                
        except Exception as e:
            self.get_logger().error(f'IK error: {str(e)}')
    
    def control_loop(self):
        """Main control loop."""
        if not self.connected:
            return
        
        for i, angle in enumerate(self.target_angles):
            self.odrive.set_position(i, angle)
            self.current_angles[i] = self.odrive.get_position(i)
        
        self.publish_joint_states()
    
    def publish_joint_states(self):
        """Publish current joint states."""
        msg = JointState()
        msg.header.stamp = self.get_clock().now().to_msg()
        msg.name = ['hip', 'knee', 'ankle']
        msg.position = self.current_angles
        msg.velocity = [0.0, 0.0, 0.0]
        msg.effort = [0.0, 0.0, 0.0]
        self.joint_states_pub.publish(msg)
    
    def execute_trajectory(self, trajectory_points):
        """Execute a list of joint angle targets.
        
        Args:
            trajectory_points: List of (hip, knee, ankle) angle tuples
        """
        for angles in trajectory_points:
            self.target_angles = list(angles)
            rclpy.spin_once(self, timeout_sec=0.01)
    
    def shutdown(self):
        """Clean shutdown."""
        if self.connected:
            self.odrive.set_idle_state(0)
            self.odrive.set_idle_state(1)
            self.odrive.set_idle_state(2)
        self.get_logger().info('Leg Controller shutdown complete')


def main(args=None):
    rclpy.init(args=args)
    controller = LegController()
    
    try:
        rclpy.spin(controller)
    except KeyboardInterrupt:
        pass
    finally:
        controller.shutdown()
        controller.destroy_node()
        rclpy.shutdown()


if __name__ == '__main__':
    main()

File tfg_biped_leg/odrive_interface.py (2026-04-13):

import time
import odrive
import asyncio
from .odrive_enums import (
    AxisState, ControlMode, 
    decode_error_enum, display_error_enum_nb, 
    ODriveError, AxisError, MotorError, 
    EncoderError, ControllerError)

import matplotlib.pyplot as plt
import matplotlib.animation as animation
import time
from typing import Callable


def _is_ipython():
    try:
        get_ipython()
        return True
    except NameError:
        return False


def _find_odrive_async(sn=None):
    """
    Async version to find ODrive, works in Jupyter notebooks.
    """
    async def _find():
        if sn is None:
            return await odrive.find_any()
        else:
            return await odrive.find_any(serial_number=sn)
    
    try:
        loop = asyncio.get_running_loop()
        coro = _find()
        return asyncio.run_coroutine_threadsafe(coro, loop).result()
    except RuntimeError:
        return asyncio.run(_find())


class IOdrive:
    default_config = {
        "current_limit": 30, # A
        "velocity_limit": 5, # turn/s
        "calibration_current": 10, # A
        "break_resistor_enabled": True,
        "pole_pairs": 7,
        "motor_torque_constant": 8.27/270, # 8.27 / motor_kv //// default odrive motor_kv = 270
        "encoder_cpr": 8192,
    }

    def __init__(self, serial_number=None):
        self.__control_mode = ControlMode.TORQUE_CONTROL
        self.odrv = self.connect_to_odrive(serial_number)
        self.odrv.clear_errors()
        self.calibrate()

    def connect_to_odrive(self, sn=None):
        """
        Connects to the first available ODrive device over USB.

        :return: An instance of the connected ODrive device.
        :raises: Exception if no device is found.
        """
        print("Searching for ODrive...")
        try:
            asyncio.get_running_loop()
            odrv = _find_odrive_async(sn)
        except RuntimeError:
            if sn is None:
                odrv = odrive.find_any()
            else:
                odrv = odrive.find_any(serial_number=sn)

        print(f"Connected to ODrive with serial number: {odrv.serial_number}")
        return odrv
    
    def calibrate(self):
        self.odrv.axis1.requested_state = AxisState.AXIS_STATE_FULL_CALIBRATION_SEQUENCE
        axis_name = "axis1"
        self.wait_for_idle(axis_name)
        print(f"{axis_name} calibration completed.")

    def enable_closed_loop(self):
        self.odrv.axis1.requested_state = AxisState.AXIS_STATE_CLOSED_LOOP_CONTROL

    def print_odrive_errors(self):
        """
        Recursively prints error fields from the ODrive, its axes, and subcomponents.

        :param odrv: An instance of the connected ODrive device.
        """
        print(f"ODrive Error: {decode_error_enum(self.odrv.error, ODriveError)}")
        
        for axis_id in [0, 1]:
            axis = getattr(self.odrv, f"axis{axis_id}")
            print(f"Axis{axis_id} Error: {decode_error_enum(axis.error, AxisError)}")
            print(f"  Motor Error: {decode_error_enum(axis.motor.error, MotorError)}")
            print(f"  Encoder Error: {decode_error_enum(axis.encoder.error, EncoderError)}")
            print(f"  Controller Error: {decode_error_enum(axis.controller.error, ControllerError)}")
    
    def print_odrive_errors_nb(self):
        """
        Recursively prints error fields from the ODrive, its axes, and subcomponents.

        :param odrv: An instance of the connected ODrive device.
        """
        print(f"ODrive Error: {display_error_enum_nb(self.odrv.error, ODriveError, 'Odrive')}")
        
        for axis_id in [0, 1]:
            axis = getattr(self.odrv, f"axis{axis_id}")
            print(f"Axis{axis_id} Error: {display_error_enum_nb(axis.error, AxisError, 'Axis')}")
            print(f"  Motor Error: {display_error_enum_nb(axis.motor.error, MotorError, 'Motor')}")
            print(f"  Encoder Error: {display_error_enum_nb(axis.encoder.error, EncoderError, 'Encoder')}")
            print(f"  Controller Error: {display_error_enum_nb(axis.controller.error, ControllerError, 'Controller')}")

    def wait_for_idle(self, axis_name: str = "axis0", poll_interval: float = 0.1) -> None:
        """
        Waits until the given axis returns to IDLE state after an operation.

        :param axis_name: Name of the axis ('axis0' or 'axis1')
        :param poll_interval: Time (in seconds) between status checks
        """
        axis = getattr(self.odrv, axis_name)
        while axis.current_state != AxisState.IDLE:
            time.sleep(poll_interval)

    def set_default_config(self):
        self.set_config(self.default_config)
        
    def set_config(self, config):
        self.odrv.axis1.motor.config.current_lim = config["current_limit"]
        self.odrv.axis1.controller.config.vel_limit = config["velocity_limit"]
        self.odrv.axis1.motor.config.calibration_current = config["calibration_current"]

        # Enable break resistor to absorb the parasite current generated when breaking
        self.odrv.config.enable_brake_resistor = config["break_resistor_enabled"]
        # If needed change the default value for the resistor, value in Ohms
        # self.odrv.config.brake_resistance = X # Ohms

        # Configure the number of pole pairs (the following values are for the official Odrive motor)
        self.odrv.axis1.motor.config.pole_pairs = config["pole_pairs"]
        self.odrv.axis1.motor.config.torque_constant = config["motor_torque_constant"] # El 8.27 es numero magico del fabricante

        # Configure encoder Counts Per Revolution (CPR) if needed, values bellow for default ODrive encoder
        self.odrv.axis1.encoder.config.cpr = config["encoder_cpr"] # CPR = PPR * 4
        self.print_config()

    def get_config(self):
        return {
            "current_limit": self.odrv.axis1.motor.config.current_lim, # A
            "velocity_limit": self.odrv.axis1.controller.config.vel_limit, # turn/s
            "calibration_current": self.odrv.axis1.motor.config.calibration_current, # A
            "break_resistor_enabled": self.odrv.config.enable_brake_resistor,
            "pole_pairs": self.odrv.axis1.motor.config.pole_pairs,
            "motor_torque_constant": self.odrv.axis1.motor.config.torque_constant, # 8.27 / motor_kv
            "encoder_cpr": self.odrv.axis1.encoder.config.cpr,
        }

    def save_config(self):
        try:
            self.odrv.save_configuration()
        except:
            self.odrv = self.connect_to_odrive()
            self.odrv.clear_errors()
            self.calibrate()
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

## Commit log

2026-04-12 Initial commit: tfg_biped_leg ROS2 package for ODrive motor control
    Features:
    - ODrive driver with USB communication
    - Forward/inverse kinematics for 3-DOF leg
    - Trajectory generation for walking gait
    - ROS2 integration with messages and services
    - Motor calibration scripts
    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
2026-04-12 feat: Add odrive_smapy motor control code and single motor test
    - Copy odrive_interface.py (IOdrive class for USB motor control)
    - Copy odrive_enums.py (ODrive state/error definitions)
    - Copy odrive_hw_interface.py (hardware interface script)
    - Copy my_config.json (D5065 motor configuration)
    - Create test_single_motor.py (single motor test script)
    - Update PROJECT_CONTEXT.md with hardware details
    - Update README.md with single motor test instructions
    Hardware: Official ODrive v3.6 + D5065 270KV motor
    [odrive_enums.py, odrive_hw_interface.py, odrive_interface.py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]
2026-04-12 docs: Update architecture and hardware documentation
    Architecture: Pi + ODrive + TCA9548A + AS5600
    - Added complete system architecture diagram
    - Added AS5600 encoder specifications (12-bit, 0x36 address)
    - Added TCA9548A I2C multiplexer info
    - Added 3-DOF joint definitions with gearbox conversion
    - Added I2C setup instructions
    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
2026-04-12 feat: Implement modular encoder architecture
    New modular encoder system with abstraction layer for Pi I2C or
    future microcontroller support:
    src/:
    - encoder_interface.py: Abstract base class with error handling
    - tca9548a.py: TCA9548A I2C multiplexer driver
    - pi_as5600_encoder.py: Pi I2C implementation for AS5600
    - serial_encoder.py: Placeholder for future microcontroller (Serial)
    - encoder_manager.py: Factory for managing multiple encoders
    - __init__.py: Package exports
    config/:
    - encoder.yaml: Encoder configuration for 3 joints
    scripts/:
    - test_encoders.py: Test script for encoder reading
    - Modular design allows switching between Pi and microcontroller
    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
    [encoder_interface.py, encoder_manager.py, pi_as5600_encoder.py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]
2026-04-12 docs: Update PROJECT_CONTEXT.md and requirements.txt
    - Update last modified date
    - Update First Use Checklist with completed items
    - Add smbus2 and pyyaml to requirements.txt for encoder code
    Commit: e0b61b6 (encoder implementation)
2026-04-13 Update docs and add odrive_test.py interactive script
    - Update README.md with complete Pi setup instructions
    - Update PROJECT_CONTEXT.md with current status and ODrive details (S/N: 35790927514957)
    - Fix relative imports in odrive_interface.py and __init__.py
    - Add odrive_test.py interactive test menu script
    - Minor fixes to test_single_motor.py
    [odrive_interface.py, odrive_test.py, test_single_motor.py]
2026-05-04 Update joint config to 2-hip + 1-knee (no ankle), add LaTeX doc with squat torque calculations, update .gitignore
2026-05-04 Fix joint rotation: Hip1=X-axis (abd/add), Hip2=Y-axis (flex/ext), update torque calcs
2026-05-08 feat: TCA9548A mux + AS5600 encoder working on channel 5; add live plot and read scripts; fix test_encoders.py paths
    [plot_encoder.py, read_encoder_ch5.py, test_encoders.py]
2026-05-08 fix: add toggle filter to AS5600 driver (rejects 215° chip-level jumps); update docs
    [pi_as5600_encoder.py, plot_encoder.py]
2026-05-08 fix: add median-3 + jump threshold filter to AS5600 driver — rejects 215° CORDIC toggle and 400-count periodic I2C bursts
    [pi_as5600_encoder.py, plot_encoder.py]
2026-05-08 docs: add ODrive v0.5.6 firmware update docs link to PROJECT_CONTEXT.md; include recorded test data
    [encoder_20260508_190630.csv, encoder_20260508_190729.csv, longtest_20260508_190842.csv]
2026-05-10 feat: add calibrate_encoder.py with encoder calibration, auto-calibrate (position ramping), and oscillation mode
    - Record 3 manual encoder limits (1/2/3) → save to YAML
    - Auto-calibrate (a): probe direction via position control (+0.5 turns),
    then ramp in 0.06-turn steps toward each AS5600 limit until within
    SAFETY_MARGIN or stall detected (velocity <0.01 turns/s for 2s)
    - Oscillation (o): sweep motor between calibrated limits
    - Modular arithmetic handles AS5600 0/4095 wrap-around
    - Uses position-only control (no velocity mode switching)
    [encoder_20260508_190630.csv, encoder_20260508_190729.csv, encoder_20260510_103938.csv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]
2026-05-10 fix: safer auto-calibrate — check both limits on each step, margin 100, slower ramp 0.15 turns/s
    [calibrate_encoder.py]
2026-05-10 fix: remove stall detection from approach_any_limit, add print errors option (e) and error display in status
    [calibrate_encoder.py]
2026-05-10 fix: oscillation now waits for motor to reach each target (poll pos_estimate); auto-calibrate skips first 5 steps to avoid same-limit re-trigger
    [calibrate_encoder.py]
2026-05-11 docs: add DH parameter derivation, FK equations, and URDF model
    - Add Denavit-Hartenberg parameter table (Z₀=forward, X₀=down, Y₀=right)
    - Add forward kinematics equations verified against URDF
    - Add URDF model from Onshape assembly (urdf/robot.urdf)
    - Add dh_kinematics.py script for FK computation
    - Update all documentation (README, PROJECT_CONTEXT, TFG_PROMPT) with correct DH frame assignment
    [part_1.stl, part_1__2.stl, part_1__3.stl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]
2026-05-27 Add CAD models section to README
    Added links to CAD models for full robot assembly and URDF model.
2026-05-27 Fix URDF model link formatting in README
2026-06-01 Update Raspberry Pi diagram in README
